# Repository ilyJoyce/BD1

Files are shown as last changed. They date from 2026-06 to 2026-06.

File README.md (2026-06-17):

# BD1-Pi

### Aufbau

Der Pi wird über das GPIO mit dem Motor-Controller verbunden:  

- IN1 = 17
- IN2 = 22
- IN3 = 23
- IN4 = 24

- ENA = 18
- ENB = 19

Siehe https://pinout.xyz/ für die Pin Nummern am Pi.  
Der Motor Controller (L298N Standard Controller Board) steuert die 4 Motoren über die Out 1 - Out 4 Schnittstellen an, Da ein Motor an Out 1 **UND** Out 2 bzw. Out 3 **UND** Out 4 angeschlossen werden *muss*, müssen die jeweils an der gleichen Seite montierten (links oder rechts) an die gleichen 2 Schnittstellen angeschlossen werden. (eg. Motor links vorne und Motor links hinten beide an Out 1 und Out 2)  

#### Spannungsquellen

Der Motor Controller wird über einen T-Connector mit einer LiPo Batterie verbunden, dessen Daten wie folgt lauten:  

- Hersteller: Gens ace
- Konfiguration: 3S, 25C
- Spannung: 11,1V
- Größe: 800mAh

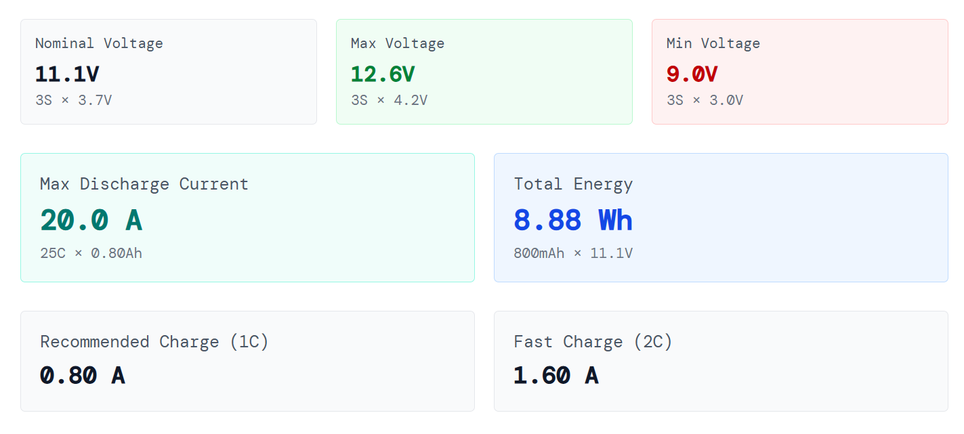
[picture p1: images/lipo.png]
LiPo daten LiPo Daten (rechnerisch)


Jede herkömmliche Powerbank mit Nenndaten von 5V und etwa 300 - 500mA kann den Raspberry Pi 3 B mit ausreichend Strom versorgen

### Steuerung

bei Nutzung eines Xbox Series S/X Controllers über Bluetooth (dieser muss manuell **einmalig** über bluetoothctl direkt über den Pi verbunden werden) funktioniert die Steuerung wie gewünscht:  
- Rechter Trigger: Vorwärts
- Linker Trigger: Rückwärts
- Linker Stick: Links und Rechts

### Liste der Elektronik-Komponenten

- Allgemeine Steuerungseinheit: Rasperry Pi3
- Motorsteuerung: L298N Motorcontroller modul
- Lidarsensor: TF Luna LiDar "single Point Lidar von Youyeeto
- Motoren: 4x DC-Getriebemotoren mit jeweils einem Reifen "4pcs DC3V-12V DC Gear Motoren for 4-wheel drive Toy Car" von Amazon(Gebildet)
- Batterie(Lastkreis): LiPo 11,1V (3S) auf Amazon
- Batterie(logikkreis): jegliche herkömmliche Powerbanks funktionieren solange sie in das Gehäuse passt
- Verkabelung: Jumper wire cables(10cm) von amazon

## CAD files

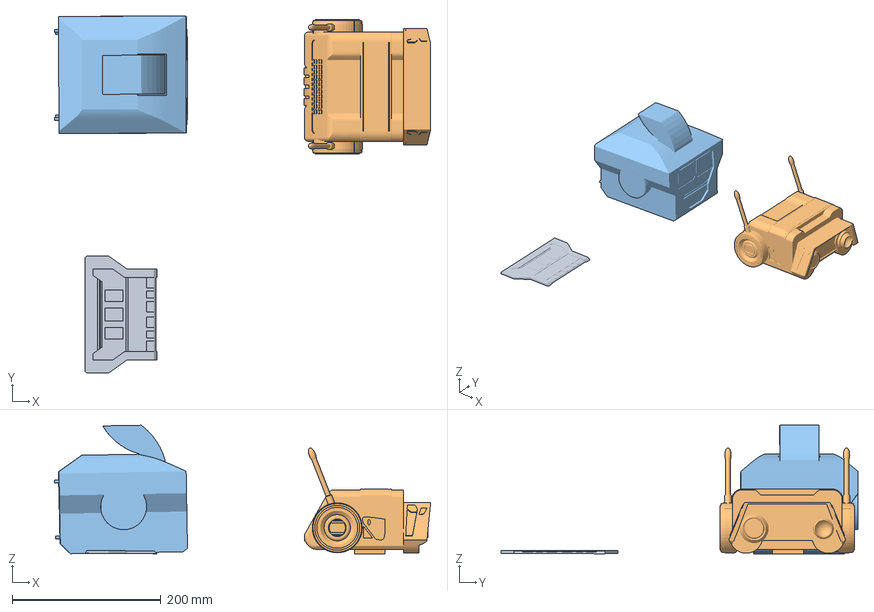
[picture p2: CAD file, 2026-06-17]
star-wars-jedi-fallen-order-bd-1-full.3mf
506.6 x 480.6 x 173.1 mm
star-wars-jedi-fallen-order-bd-1-full.stl_A_B_B_B
Sub-merged Körper_A
star-wars-jedi-fallen-order-bd-1-full.stl_A_A
Sub-merged Körper_B

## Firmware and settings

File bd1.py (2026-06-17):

import serial
import threading
import time

import pygame
import RPi.GPIO as gpio

# =====================================
# TF-Luna Configuration
# =====================================

PORT = "/dev/ttyUSB0" # Serial Port (sollte bei gleichem Aufbau gleich sein)

# NICHT VERÄNDERN!! liest den TF Luna aus

BAUD_RATE = 115200

CLIFF_THRESHOLD = 30      # cm
CLIFF_CONFIRMATIONS = 3   # consecutive readings
COOLDOWN = 0.5            # seconds

distance_cm = 9999
distance_timestamp = 0

ser = serial.Serial(PORT, BAUD_RATE, timeout=1)

# =====================================
# GPIO Setup (Verbindung zwischen Controller und PI)
# =====================================

IN1 = 17
IN2 = 22
IN3 = 23
IN4 = 24

ENA = 18
ENB = 19

gpio.setmode(gpio.BCM)

for pin in (IN1, IN2, IN3, IN4, ENA, ENB):
    gpio.setup(pin, gpio.OUT)

pwmA = gpio.PWM(ENA, 1000)
pwmB = gpio.PWM(ENB, 1000)

pwmA.start(0)
pwmB.start(0)

# =====================================
# TF-Luna Reader Thread (Liest den Luna immer wieder in einem eigenen Thread aus, um während der Steuerung lesen zu können)
# =====================================

def lidar_thread():
    global distance_cm
    global distance_timestamp

    while True:
        try:
            if ser.read() == b'\x59':
                if ser.read() == b'\x59':

                    frame = ser.read(7)

                    if len(frame) == 7:
                        distance_cm = frame[0] + frame[1] * 256
                        distance_timestamp = time.time()

        except Exception as e:
            print("LiDAR Error:", e)
            time.sleep(0.1)

# =====================================
# Motor Control
# =====================================

def set_motors(left_speed, right_speed):
    """
    Speed range:
    -100 to 100
    """

    # Left motor
    if left_speed > 0:
        gpio.output(IN1, True)
        gpio.output(IN2, False)

    elif left_speed < 0:
        gpio.output(IN1, False)
        gpio.output(IN2, True)
    else:
        gpio.output(IN1, False)
        gpio.output(IN2, False)

    # Right motor
    if right_speed > 0:
        gpio.output(IN3, False)
        gpio.output(IN4, True)
    elif right_speed < 0:
        gpio.output(IN3, True)
        gpio.output(IN4, False)
    else:
        gpio.output(IN3, False)
        gpio.output(IN4, False)

    pwmA.ChangeDutyCycle(min(abs(left_speed), 100))
    pwmB.ChangeDutyCycle(min(abs(right_speed), 100))


def stop():
    set_motors(0, 0)

# =====================================
# Controller Setup
# =====================================

pygame.init()
pygame.joystick.init()

# Jeder Bluetooth Controller sollte funktionieren, nicht getestet (sticks und bumper könnten untereinander vertauscht sein - Siehe "Controller Input" weiter unten)
# Getestet: Xbox Series S/X Controller mit bluetooth (standart ausstattung)

if pygame.joystick.get_count() == 0:
    raise Exception("No controller detected")

controller = pygame.joystick.Joystick(0)
controller.init()

print("Connected:", controller.get_name())

# =====================================
# Start LiDAR Thread
# =====================================

threading.Thread(
    target=lidar_thread,
    daemon=True
).start()

last_cliff_time = 0
cliff_count = 0

# =====================================
# Main Loop
# =====================================

try:

    while True:

        pygame.event.pump()

        now = time.time()

        # Ignore stale measurements
        reading_is_fresh = (
            now - distance_timestamp
        ) < 0.1

        # =================================
        # Cliff Detection
        # =================================

        if reading_is_fresh:

            if distance_cm > CLIFF_THRESHOLD:
                cliff_count += 1
            else:
                cliff_count = 0

        if (
            reading_is_fresh
            and cliff_count >= CLIFF_CONFIRMATIONS
            and (now - last_cliff_time) > COOLDOWN
        ):

            print(
                f"CLIFF DETECTED! Distance: {distance_cm} cm"
            )

            # Immediate reverse override
            set_motors(-55, -55)

            # Block controller
            time.sleep(0.5)

            stop()

            # Throw away buffered TF-Luna packets
            ser.reset_input_buffer()

            # Wait for fresh measurement
            old_timestamp = distance_timestamp

            timeout_start = time.time()

            while (
                distance_timestamp == old_timestamp
                and time.time() - timeout_start < 1
            ):
                time.sleep(0.005)

            cliff_count = 0
            last_cliff_time = time.time()

            continue

        # =================================
        # Controller Input
        # =================================

	# Setup der Achsen (sticks und bumper - hier kann die konfiguration geändert werden, für die gewünschten tasten)

        # Left stick horizontal
        steer = controller.get_axis(0)

        # Triggers
        left_trigger = (
            controller.get_axis(5) + 1
        ) / 2

        right_trigger = (
            controller.get_axis(4) + 1
        ) / 2

        # ---------------------------------
        # Rotate in place (tank steering)
        # ---------------------------------

        if abs(steer) > 0.20:

            turn_speed = abs(steer) * 65 # Faktor bestimmt geschwindigkeit (Limit 100)

            if steer > 0:
                # Rotate right
                set_motors(
                    -turn_speed,
                    turn_speed
                )

            else:
                # Rotate left
                set_motors(
                    turn_speed,
                    -turn_speed
                )

        # ---------------------------------
        # Forward
        # ---------------------------------

        elif right_trigger > 0.05:

            speed = right_trigger * 100 # Faktor bestimmt geschwindigkeit (Limit 100)
            print("FORWARD:", speed)
            set_motors(
                speed,
                speed
            )

        # ---------------------------------
        # Reverse
        # ---------------------------------

        elif left_trigger > 0.05:

            speed = left_trigger * 65 # Faktor bestimmt geschwindigkeit (Limit 100)
            print("REVERSE:", speed)

            set_motors(
                -speed,
                -speed
            )

        else:
            stop()

        time.sleep(0.02)

except KeyboardInterrupt:
    print("\nStopping...")

finally:

    stop()

    pwmA.stop()
    pwmB.stop()

    gpio.cleanup()

    pygame.quit()

    ser.close()

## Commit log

2026-06-17 add 3D model
    [star-wars-jedi-fallen-order-bd-1-full.3mf]
2026-06-17 Update README with LiPo data and component details
    Added LiPo battery image and updated component list.
